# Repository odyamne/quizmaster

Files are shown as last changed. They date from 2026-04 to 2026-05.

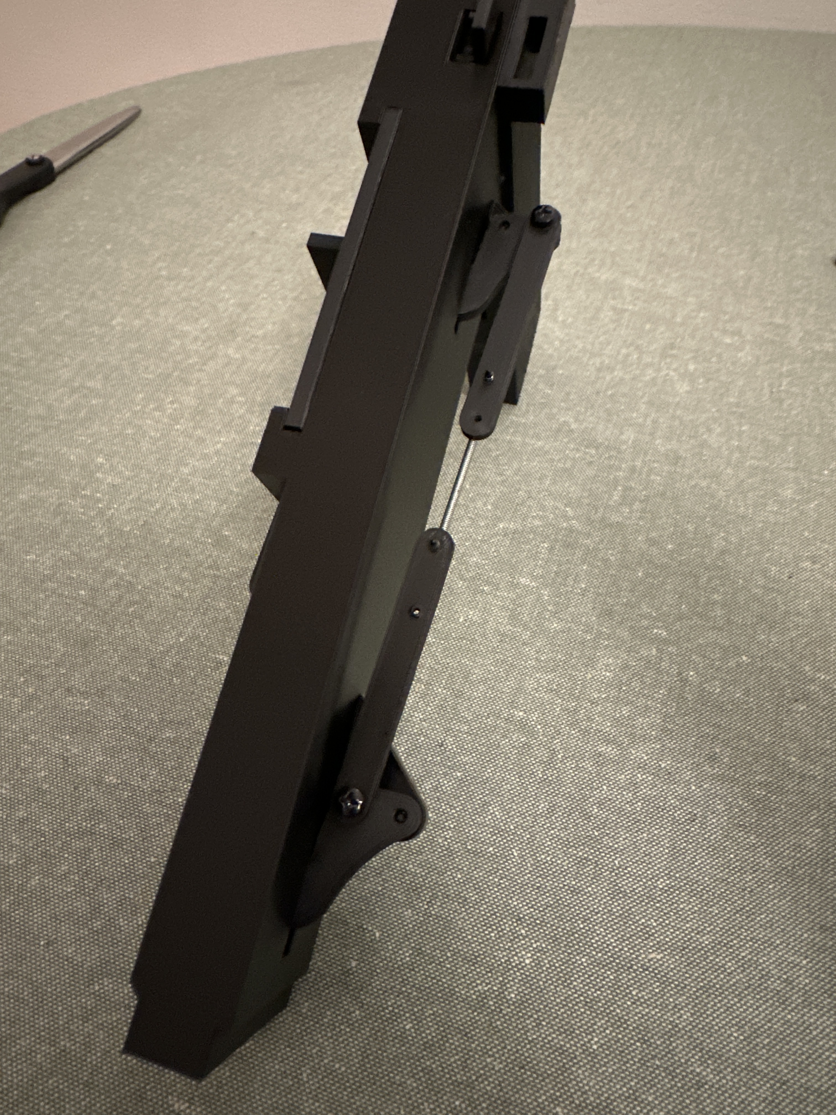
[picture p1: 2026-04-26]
Fotod/printimine/IMG_5341.JPG

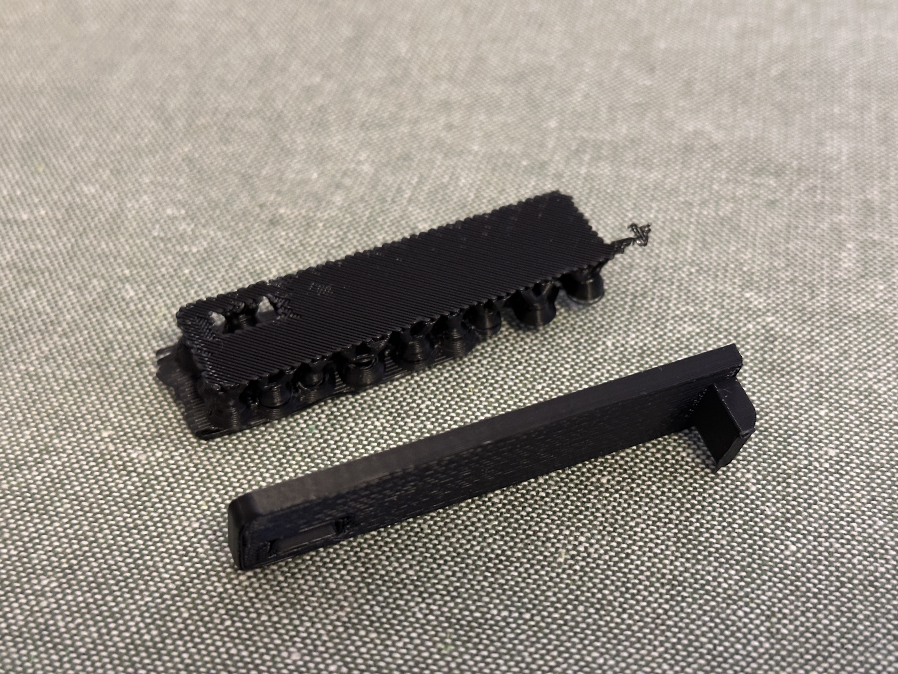
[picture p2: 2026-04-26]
Fotod/printimine/IMG_5337.JPG

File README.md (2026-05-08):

# DTI Interaktiivne Robot: Prototüüp "Quizmaster"

Käesolev repositoorium sisaldab Tallinna Ülikooli Digitehnoloogiate Instituudi (DTI) bakalaureusetöö raames arendatud sotsiaalse roboti prototüübi tehnilist dokumentatsiooni, tarkvara ja disainifaile. Projekti eesmärk on luua interaktiivne vahend, mis tutvustab IKT-valdkonda läbi mängustatud viktoriini ja füüsilise preemiamehhanismi.

## Repositooriumi struktuur

Süsteem on jaotatud neljaks põhivaldkonnaks, mis vastavad repositooriumi juurkataloogidele:

- **[/CAD](./CAD)** – Roboti korpuse ja mehaaniliste detailide mudelid (Solid Edge 2024).
  - `assembly/` – Seadme koostefailid (.par).
  - `stl/` – 3D-printimiseks valmis detailid.
  - `pleksi_loige.dft` – Joonis pleksiklaasi CNC- või laserlõikuse jaoks.
- **[/Fritzing](./Fritzing)** – Elektroonika komponentide ühendusskeem.
- **[/Lähtekood](./Lähtekood)** – Süsteemi tarkvaraline arhitektuur.
  - `esp32/` – Alamkontrolleri tarkvara (C++) servomootorite ja LED-ide juhtimiseks.
  - `frontend/` – Veebipõhine kasutajaliides (HTML/JS/CSS).
  - `main.py` – Kesksüsteemi loogika (Python/FastAPI).
  - `questions.json` – Muudetav viktoriini küsimuste baas.
- **[/Fotod](./Fotod)** – Visuaalne dokumentatsioon arendusprotsessist ja riistvara komponentidest.

## Tehniline teostus

### Põhifunktsioonid

- **Autonoomne tuvastus:** mmWave radari abil tajub robot lähenevaid inimesi ja algatab interaktsiooni.
- **Mängustatud viktoriin:** Interaktsioon toimub 7" ekraani ja taktiilset tagasisidet pakkuvate arkaadnuppude abil.
- **Mehaaniline väljastus:** Servomootoritega juhitud kaheastmeline premeerimissüsteem maiustuste väljastamiseks.
- **Multimeedia:** Animeeritud silmad ja sünteesitud eestikeelne kõne (TTS).

### Riistvaraline arhitektuur

Süsteem kasutab hajutatud arvutusmudelit:

- **Keskarvuti:** Raspberry Pi 4B - tegeleb backendi, frontendi, multimeedia ja anduritega.
- **Alamkontroller:** NodeMCU ESP32 - juhib servomootoreid ja LED-ribasid.
- **Toide:** X728 UPS HAT - stabiilse voolu tagamiseks ja `power_monitor.py` energiatarbe halduseks.
- **Signaali terviklikkus:** Kasutatud on loogikanivoo muundurit ja LED-ribade andmeliinidel 330 Ω takisteid.

### Disain ja valmistamine

Kõik detailid on modelleeritud **Solid Edge 2024** tarkvaraga. Valmistamisel on kasutatud 3D-printimise tehnoloogiat PLA plast filamendiga ja pleksiklaasi CNC-lõikust.

## Kasutamine

1.  **Riistvara:** Pane süsteem kokku järgides [/Fritzing](./Fritzing) kataloogis olevat elektriskeemi.
2.  **Süsteemi seadistamine:**
    - Paigalda vajalikud Pythoni teegid: `pip install -r requirements.txt`.
    - Laadi `esp32/` kood ESP32 mikrokontrollerisse kasutades selleks Arduino IDE.
    - Ühenda X728 UPS HAT autoboot viikudele "jumper".
3.  **Käivitamine:** Käivita kesksüsteem käsuga `python main.py`. Pärast toite ühendamist ja nupu vajutust käivitub roboti autonoomne režiim ning ootab interaktsiooni.

## Litsents

- **Tarkvara** ([/Lähtekood](./Lähtekood)): [MIT litsents](https://opensource.org/licenses/MIT).
- **Disain ja skeemid** ([/CAD](./CAD), [/Fritzing](./Fritzing)): [Creative Commons Attribution 4.0 International (CC BY 4.0)](https://creativecommons.org/licenses/by/4.0/).

## Autorid

- **Ander Aava & Taavi Vendt**
- **Juhendajad:** Kalle Kivi ja Triinu Jesmin
- **Tehniline konsultant:** Tanel Toova

---

_Tallinna Ülikool, Digitehnoloogiate Instituut (2026)_

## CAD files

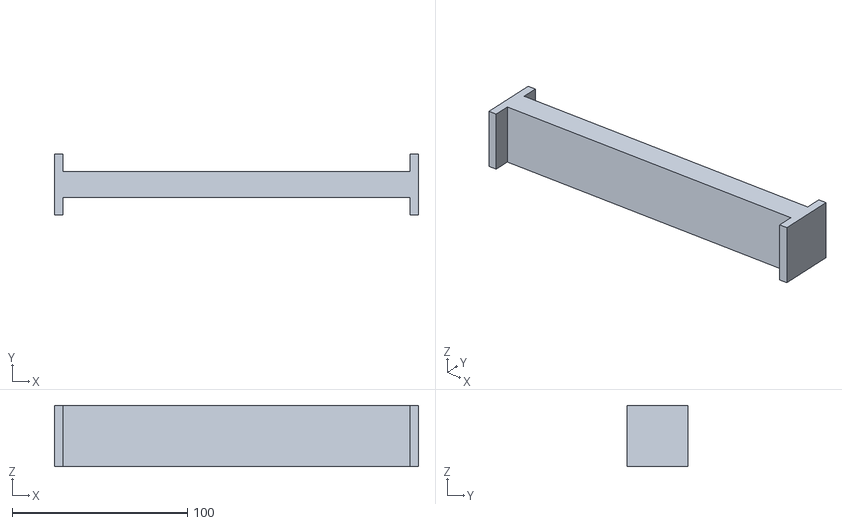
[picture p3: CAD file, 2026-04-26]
CAD/stl/salve_laadimis_abiline.stl
208.0 x 35.0 x 35.0

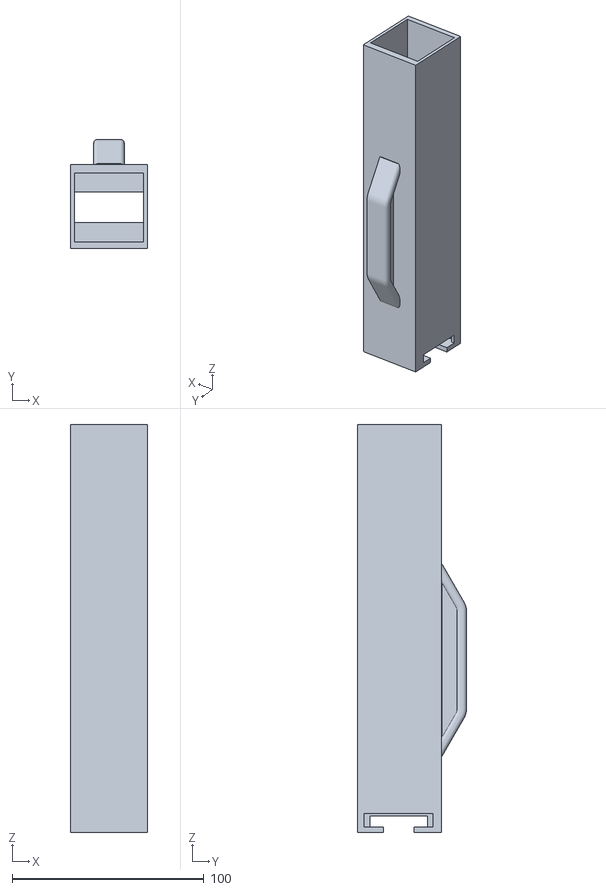
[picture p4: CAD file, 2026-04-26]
CAD/stl/teal/shoko_salv.stl
40.0 x 57.0 x 213.0

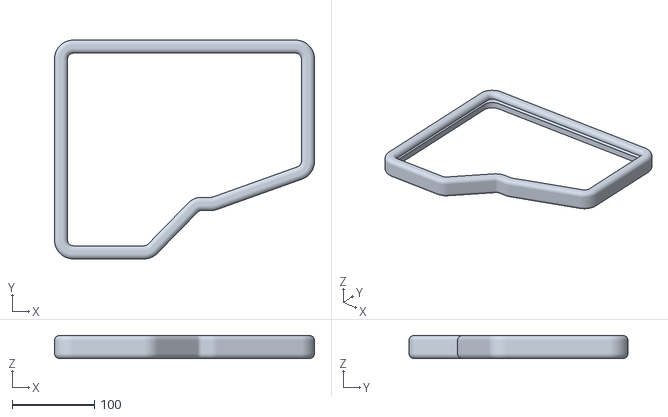
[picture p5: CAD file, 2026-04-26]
CAD/stl/transparent/led_trim.stl
316.0 x 266.0 x 28.0

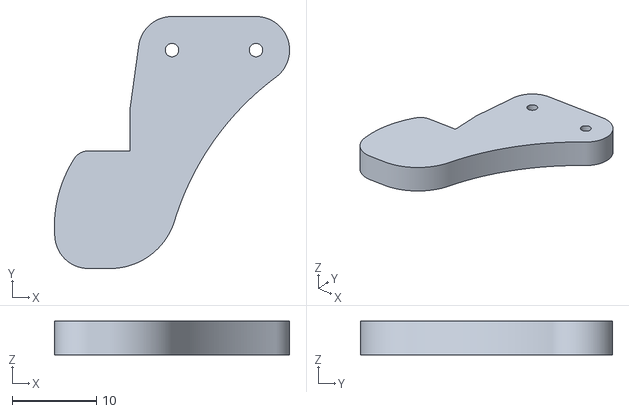
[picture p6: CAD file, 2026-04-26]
CAD/stl/white/shoko_pidur.stl
28.0 x 30.0 x 4.00

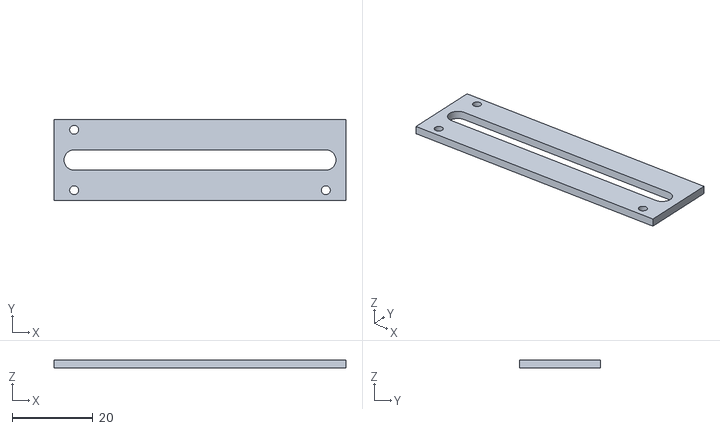
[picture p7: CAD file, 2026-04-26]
CAD/stl/teal/salve_lukusti_kate.stl
72.5 x 20.0 x 2.00

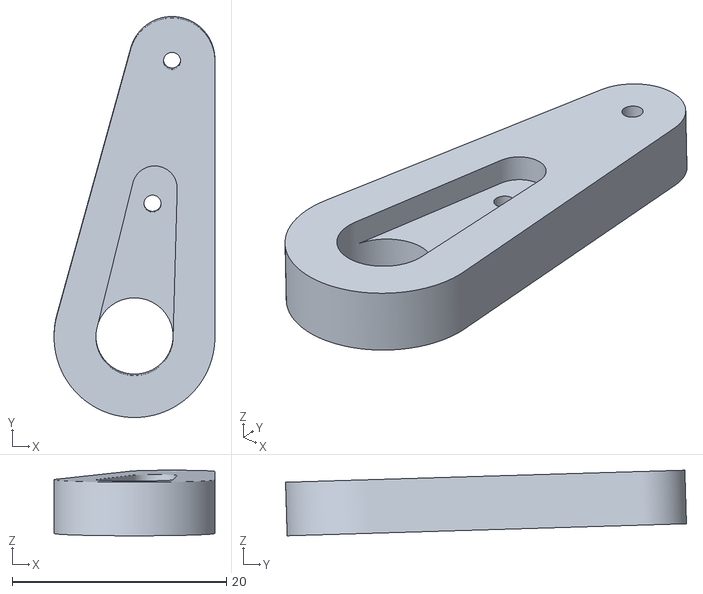
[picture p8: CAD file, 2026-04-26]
CAD/stl/white/crank_servole.stl
15.0 x 37.4 x 6.12

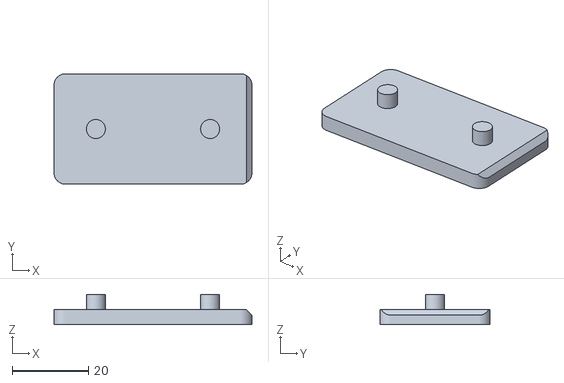
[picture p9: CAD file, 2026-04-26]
CAD/stl/teal/dispenser_laadija_kelk.stl
52.0 x 29.0 x 8.00

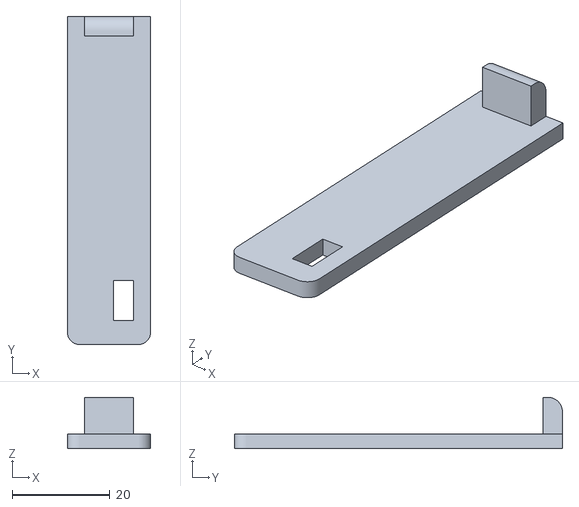
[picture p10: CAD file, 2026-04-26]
CAD/stl/white/dispenser_kelk_tommits.stl
17.0 x 67.0 x 10.5

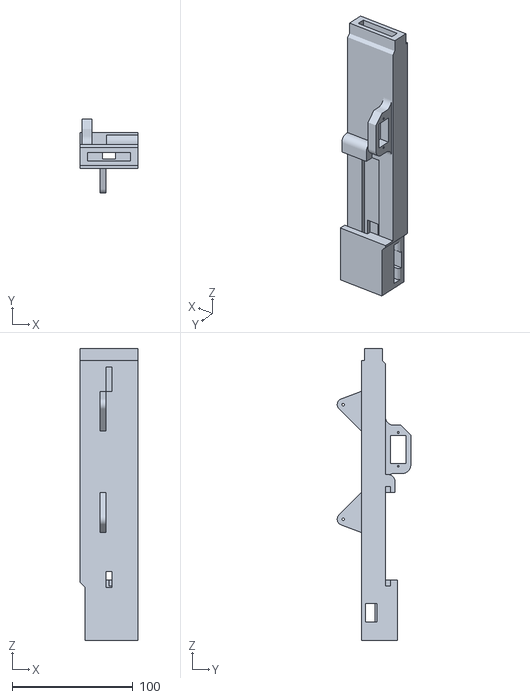
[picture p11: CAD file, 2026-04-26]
CAD/stl/teal/dispenser_kelk_raam.stl
48.0 x 61.0 x 242.0

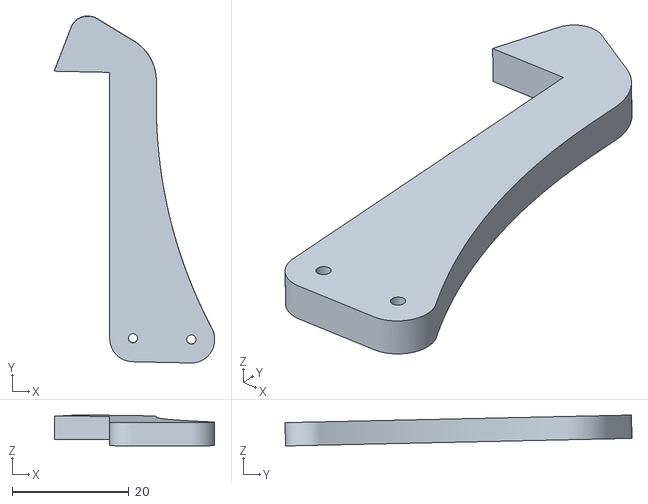
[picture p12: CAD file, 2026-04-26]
CAD/stl/white/uus_shoko_pidur.stl
27.5 x 59.5 x 5.30

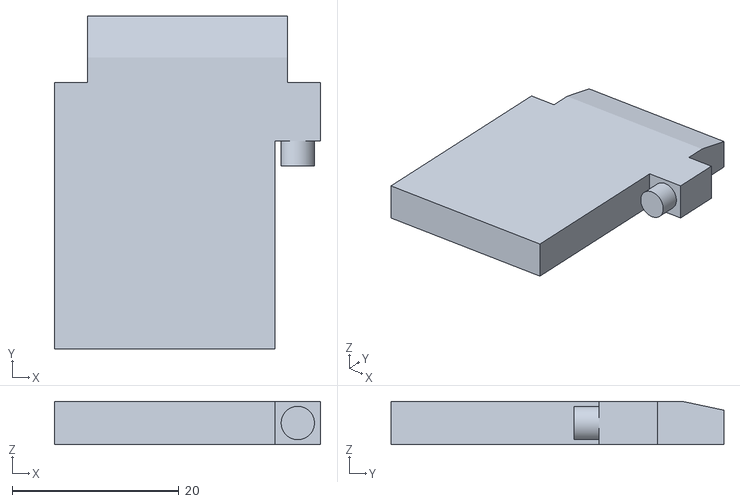
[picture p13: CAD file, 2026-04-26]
CAD/stl/teal/dispenser_kinnitus.stl
32.0 x 40.0 x 5.20

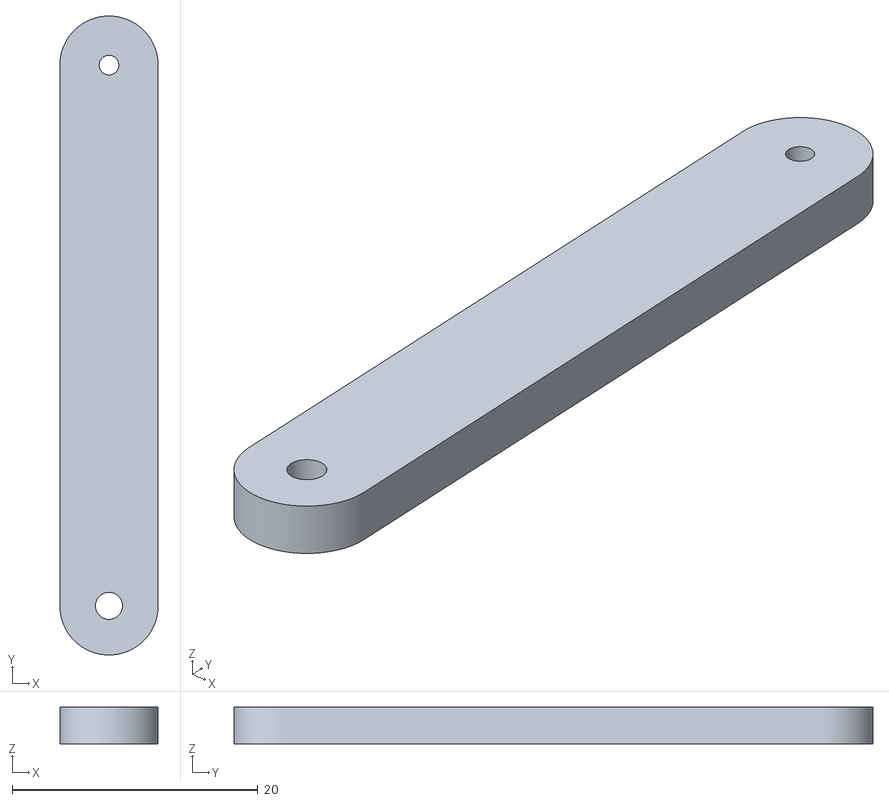
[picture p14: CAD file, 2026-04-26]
CAD/stl/white/piduri_link.stl
8.00 x 52.0 x 3.00

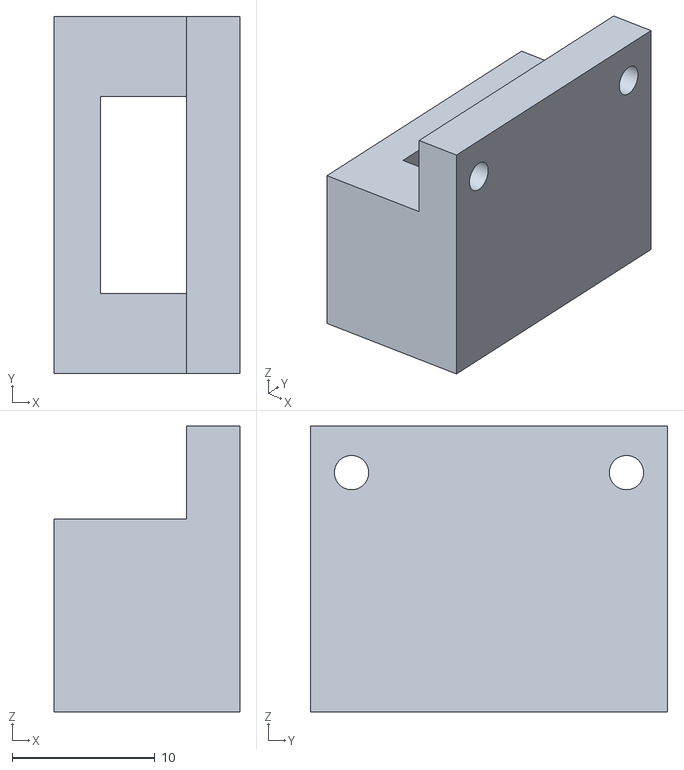
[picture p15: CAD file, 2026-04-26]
CAD/stl/teal/usb_a_pesa.stl
13.0 x 25.0 x 20.0

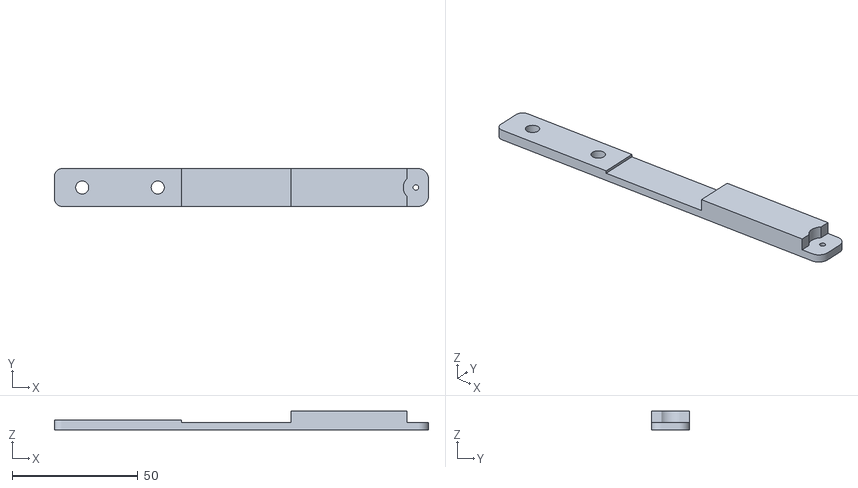
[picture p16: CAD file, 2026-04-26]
CAD/stl/white/dispenser_laadija_liugur.stl
148.5 x 15.0 x 7.50

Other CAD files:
CAD/stl/transparent/led_trim_mir.stl
CAD/stl/teal/salve_lukusti.stl
CAD/stl/white/salve_magnet_klots.stl
CAD/stl/teal/dispenser_crank_link.stl
CAD/stl/teal/PD_klamber.stl
CAD/stl/teal/crank_liiges.stl
CAD/stl/teal/ekraani_klamber.stl
CAD/stl/teal/servo_bottom_pesa_kaas.stl
CAD/stl/white/crank_kinnitus.stl
CAD/stl/white/dispenser_kelk_kate.stl
CAD/stl/white/dispenser_servo_crank.stl
CAD/stl/white/robot_kere_koost.stl

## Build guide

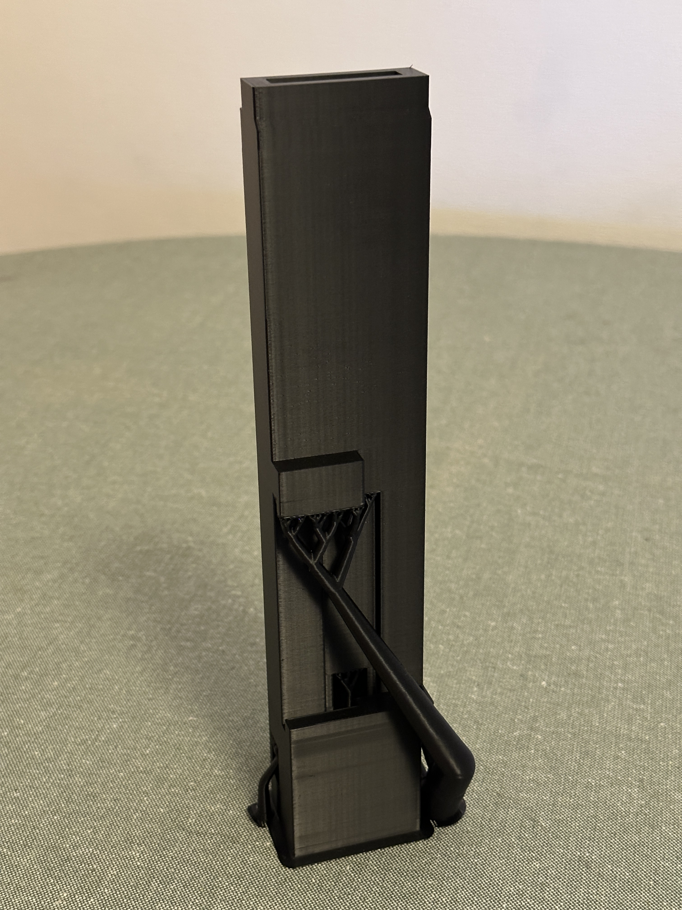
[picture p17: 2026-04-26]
Fotod/printimine/IMG_5334.JPG

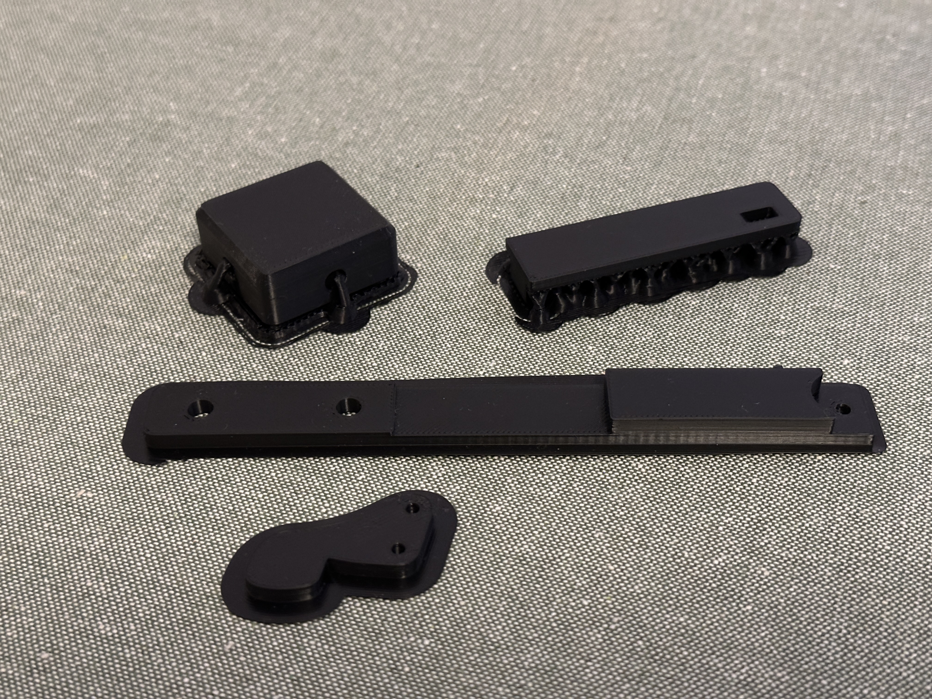
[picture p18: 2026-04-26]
Fotod/printimine/IMG_5335.JPG

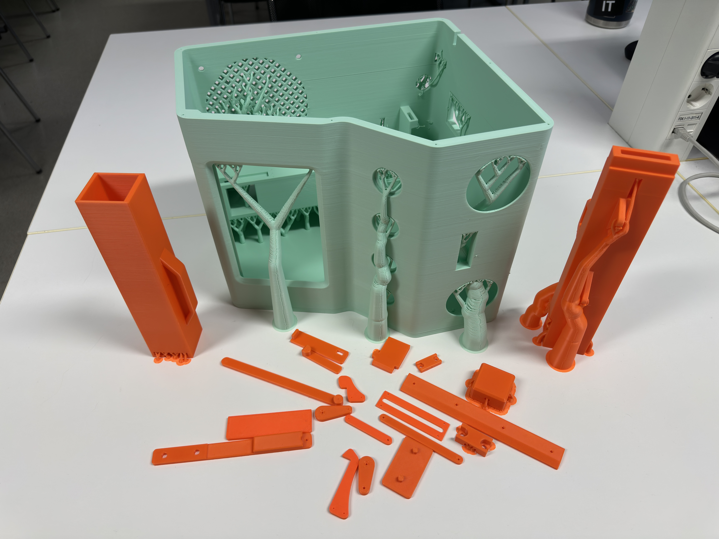
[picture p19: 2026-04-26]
Fotod/printimine/IMG_5527.JPG

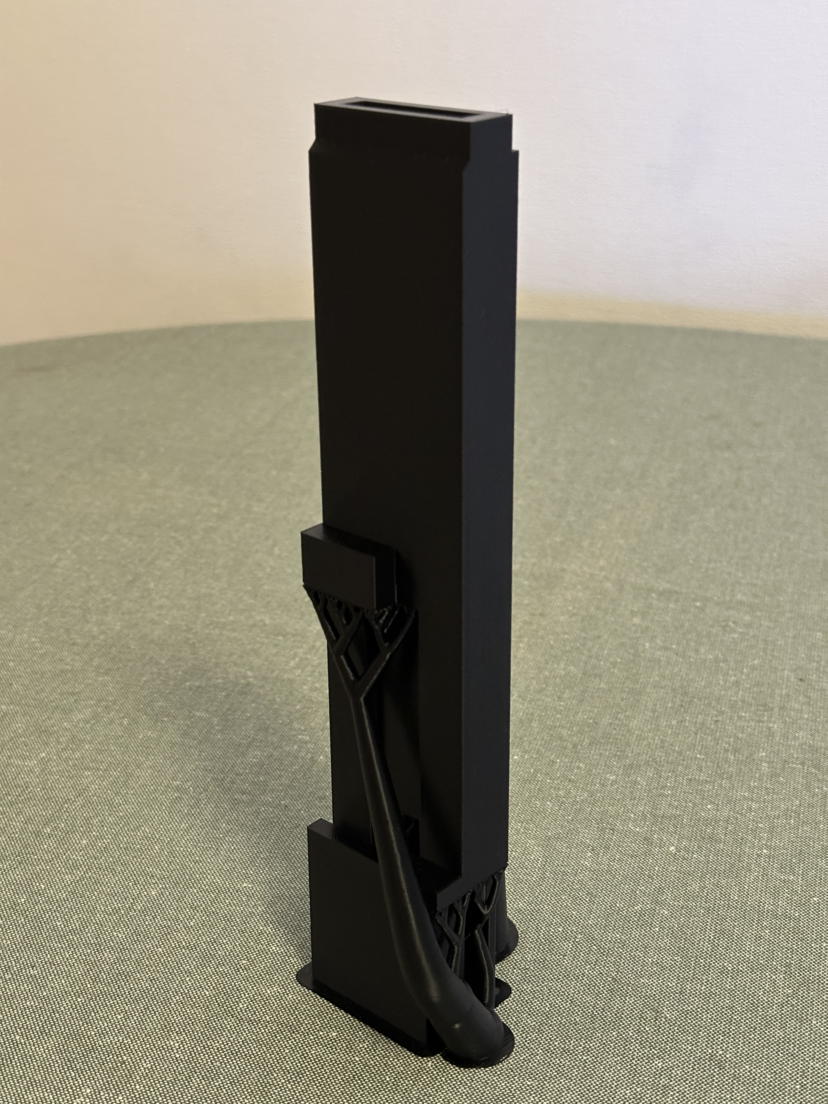
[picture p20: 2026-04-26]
Fotod/printimine/IMG_5333.JPG

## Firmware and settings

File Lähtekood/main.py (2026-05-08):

import asyncio
import json
import random
import serial
import time
from contextlib import asynccontextmanager
from fastapi import FastAPI, WebSocket, WebSocketDisconnect
from fastapi.staticfiles import StaticFiles
from gpiozero import Button, LED, DigitalInputDevice
import uvicorn

# ==========================================
# GLOBAALSED MUUTUJAD JA OLEKUD
# ==========================================
main_loop = None
STATE = "IDLE"  # Võimalikud: ERROR, IDLE, ACTIVE, QUIZ, REWARD

# Riistvara pordid
RADAR_PORT = '/dev/ttyAMA4'
ESP_PORT = '/dev/ttyUSB0'  # Või /dev/ttyACM0

# Quiz taimer
quiz_last_activity = 0
QUIZ_TIMEOUT = 30  # Sekundit, enne kui robot tüdineb

questions_db = []
current_question = None

# ==========================================
# ANDMEBAASI LAADIMINE
# ==========================================
def load_questions():
    try:
        with open("questions.json", "r", encoding="utf-8") as f:
            return json.load(f)
    except FileNotFoundError:
        print("VIGA: questions.json faili ei leitud!")
        return []

questions_db = load_questions()

def get_random_question():
    if not questions_db:
        return {"question": "VIGA: Andmebaas tühi!", "answers": {"A": "-", "B": "-", "C": "-", "D": "-"}, "correct_btn": "A"}
    return random.choice(questions_db)

# ==========================================
# ESP32 JA RADAR (JADAÜHENDUSED)
# ==========================================
esp_serial = None
radar_serial = None

try:
    esp_serial = serial.Serial(ESP_PORT, 115200, timeout=1)
    print("ESP32 ühendatud!")
except:
    print(f"VIGA: ESP32 ei leitud pordilt {ESP_PORT}")

try:
    radar_serial = serial.Serial(RADAR_PORT, 115200, timeout=1)
    print("Radar ühendatud!")
except:
    print(f"VIGA: Radariti ei leitud pordilt {RADAR_PORT}")

def send_esp_command(cmd: str):
    """Saadab käsu üle USB ESP32-le"""
    if esp_serial:
        try:
            esp_serial.write((cmd + '\n').encode('utf-8'))
        except Exception as e:
            print(f"ESP saatmise viga: {e}")

# ==========================================
# NUPUD JA HALL SENSOR
# ==========================================
hardware_events = asyncio.Queue()

try:
    btn_A = Button(17, pull_up=True, bounce_time=0.1) # Punane
    led_A = LED(27)
    btn_B = Button(23, pull_up=True, bounce_time=0.1) # Roheline
    led_B = LED(22)
    btn_C = Button(24, pull_up=True, bounce_time=0.1) # Sinine
    led_C = LED(25)
    btn_D = Button(16, pull_up=True, bounce_time=0.1)  # Kollane
    led_D = LED(13)
    
    # Hall sensor šokolaadi jaoks
    hall_sensor = DigitalInputDevice(18, pull_up=True)
    hardware_available = True
except Exception as e:
    print(f"GPIO viga: {e}")
    hardware_available = False

def turn_all_leds(state: bool):
    if not hardware_available: return
    if state:
        led_A.on(); led_B.on(); led_C.on(); led_D.on()
    else:
        led_A.off(); led_B.off(); led_C.off(); led_D.off()

# ==========================================
# OLEKUMASINA/FSM LOOGIKAL ALGORITM
# ==========================================
def change_state(new_state):
    global STATE, current_question, quiz_last_activity
    if STATE == new_state: return
    STATE = new_state
    print(f"--- UUS OLEK: {STATE} ---")

    # Teavita brauserit oleku muutusest
    if main_loop:
        main_loop.call_soon_threadsafe(hardware_events.put_nowait, {"event": "STATE_CHANGE", "state": STATE})

    if STATE == "IDLE":
        # turn_all_leds(False)
        send_esp_command("LED_IDLE")
        
    elif STATE == "ACTIVE":
        # Heli: "Hei! Astu ligi!"
        # Siin saad hiljem kutsuda nt: play_audio("tervitus.wav")
        # turn_all_leds(True)
        send_esp_command("LED_IDLE")

    elif STATE == "QUIZ":
        quiz_last_activity = time.time()
        turn_all_leds(True)
        current_question = get_random_question()
        if main_loop:
            main_loop.call_soon_threadsafe(hardware_events.put_nowait, {
                "event": "START_QUIZ",
                "question": current_question["question"],
                "answers": current_question["answers"],
                "correct_btn": current_question["correct_btn"]
            })
            
    elif STATE == "REWARD":
        turn_all_leds(False)
        # Heli: "Suurepärane! Siin on sulle auhind!"
        send_esp_command("LED_WIN")
        send_esp_command("DISPENSE")
        # Premeerimise lõpetab eraldi taustaprotsess (vaata allpool)

    elif STATE == "ERROR":
        turn_all_leds(False)
        send_esp_command("LED_OFF")

# ==========================================
# SÜNDMUSTE KÄSITLEJAD (Nupud & Sensor)
# ==========================================
def on_button_pressed(btn_name):
    global quiz_last_activity
    
    if STATE == "ERROR":
        # Kui oleme hoolduses, ainult ROHELINE nupp teeb midagi (kinnitab täitmise)
        if btn_name == "B" and not hall_sensor.is_active:
            print("Hooldus kinnitatud. Masin korras!")
            change_state("IDLE")
        return

    if STATE == "ACTIVE":
        # Inimene vajutas nuppu, lähme viktoriini!
        change_state("QUIZ")
        return

    if STATE == "QUIZ":
        quiz_last_activity = time.time() # Nullime taimeri
        
        # Saada vajutus UI-le visuaaliks
        if main_loop:
            main_loop.call_soon_threadsafe(hardware_events.put_nowait, {"event": "BUTTON_PRESS", "button": btn_name})
        
        # Kontrollime vastust
        if btn_name == current_question["correct_btn"]:
            change_state("REWARD")
            # Käivitame asünkroonse ootaja, mis viib tagasi IDLE olekusse pärast servo tsüklit
            if main_loop:
                main_loop.create_task(reward_sequence())
        else:
            # Heli: "Vale vastus, proovi uuesti!"
            pass 

def on_hall_sensor_changed():
    """Kutsutakse välja, kui magnet fikseerib salve tühjenemise"""
    if hall_sensor.is_active:
        print("HÄIRE: Šokolaad on otsas!")
        change_state("ERROR")
    else:
        # Magnet võeti ära, järelikult hooldaja võttis salve välja
        if STATE == "ERROR":
            print("Hooldus: Salv eemaldatud. Ootan rohelist nuppu...")
            if main_loop:
                main_loop.call_soon_threadsafe(hardware_events.put_nowait, {"event": "MAINTENANCE_MODE"})

if hardware_available:
    btn_A.when_pressed = lambda: on_button_pressed("A")
    btn_B.when_pressed = lambda: on_button_pressed("B")
    btn_C.when_pressed = lambda: on_button_pressed("C")
    btn_D.when_pressed = lambda: on_button_pressed("D")
    
    # Magnetanduri sündmused
    hall_sensor.when_activated = on_hall_sensor_changed
    hall_sensor.when_deactivated = on_hall_sensor_changed

# ==========================================
# TAUSTAPROTSESSID (Radar & Taimerid)
# ==========================================
async def reward_sequence():
    """Ootab servo väljastustsükli lõppu ja taastab ooterežiimi"""
    await asyncio.sleep(8) # ESP tsükkel võtab ca 8 sek
    if STATE == "REWARD": # Veendume, et vahepeal pole magnet salv tühjenenud
        change_state("IDLE")

async def led_blinker_task():
    """Haldab nuppude LED-ide animatsioone"""
    if not hardware_available:
        return
        
    # Nuppude LED-ide haldus
    leds = [led_A, led_B, led_C, led_D]
    wave_index = 0
    wave_direction = 1
    blink_state = False

    while True:
        if STATE == "IDLE":
            # Lainetuse (wave) rütm edasi-tagasi
            for i, led in enumerate(leds):
                if i == wave_index:
                    led.on()
                else:
                    led.off()
            
            # Arvutame järgmise tule indeksi
            wave_index += wave_direction
            if wave_index >= len(leds) - 1:
                wave_direction = -1  # Pöörab suuna tagasi
            elif wave_index <= 0:
                wave_direction = 1   # Pöörab suuna edasi
                
            await asyncio.sleep(0.3) # Laine liikumise kiirus (väiksem = kiirem)

        elif STATE == "ACTIVE":
            # Kõik nupud vilguvad sünkroonis
            blink_state = not blink_state
            turn_all_leds(blink_state)
            await asyncio.sleep(0.5) # Vilkumise kiirus (0.5s sees, 0.5s väljas)
            
        else:
            # Muudes olekutes (QUIZ, REWARD, ERROR) me animatsiooni ei tee
            # Tulede staatilise oleku määrab `change_state()` funktsioon
            await asyncio.sleep(0.5)

async def radar_listener():
    last_seen_time = 0
    presence_start_time = None  # Stopperi algusaeg
    REQUIRED_PRESENCE = 5.0     # Mitu sekundit peab inimene paigal seisma
    
    while True:
        if radar_serial and radar_serial.in_waiting > 0:
            try:
                line = radar_serial.readline().decode('utf-8').strip()
                # Puhastame sisendi ja teisendame numbriks
                distance = int(''.join(filter(str.isdigit, line))) 
                
                # Silumiseks saadame endiselt andmed HUDi (lõpus eemaldame)
                if main_loop:
                    main_loop.call_soon_threadsafe(hardware_events.put_nowait, {
                        "event": "RADAR_DEBUG", 
                        "distance": distance
                    })

                if distance < 100: 
                    last_seen_time = time.time() # Viimati nähtud üldse
                    
                    # Kui keegi just sisenes, paneme stopperi käima
                    if presence_start_time is None:
                        presence_start_time = time.time()
                        print("Radar: Keegi sisenes tsooni, alustan ootamist...")

                    # Kontrollime, kas 5 sekundit on täis
                    elapsed = time.time() - presence_start_time
                    if STATE == "IDLE" and elapsed >= REQUIRED_PRESENCE:
                        print(f"Radar: Inimene on viibinud tsooni {REQUIRED_PRESENCE}s. Aktiveerin!")
                        change_state("ACTIVE")
                else:
                    # Kui vaateväli on tühi, nullime stopperi koheselt
                    if presence_start_time is not None:
                        print("Radar: Tsoon tühjenes, nullin stopperi.")
                    presence_start_time = None
                    
            except Exception as e:
                # ignoreeri lugemisvigu
                pass
                
        # Kui oleme ACTIVE olekus ja kedagi pole näha olnud 3 sekundit, läheb IDLE-sse
        if STATE == "ACTIVE" and (time.time() - last_seen_time > 3.0):
            change_state("IDLE")
            presence_start_time = None # Igaks juhuks nullime ka siin
            
        await asyncio.sleep(0.05)

async def quiz_timeout_watcher():
    """Põgenemise stsenaarium: Viskab mängust välja, kui nuppu ei vajutata"""
    while True:
        if STATE == "QUIZ" and (time.time() - quiz_last_activity > QUIZ_TIMEOUT):
            print("TIMEOUT: Inimene lahkus mängu ajal.")
            change_state("IDLE")
        await asyncio.sleep(1)

# ==========================================
# FASTAPI JA SÜSTEEMI KÄIVITUMINE
# ==========================================
@asynccontextmanager
async def lifespan(app: FastAPI):
    global main_loop
    main_loop = asyncio.get_running_loop()
    
    # Käivitame taustaprotsessid
    asyncio.create_task(broadcast_hardware_events())
    asyncio.create_task(radar_listener())
    asyncio.create_task(quiz_timeout_watcher())
    asyncio.create_task(led_blinker_task())
    
    # Kontrollime kohe alguses, kas šokolaadi on
    if hardware_available and hall_sensor.is_active:
        change_state("ERROR")
    else:
        change_state("IDLE")
        
    yield

app = FastAPI(lifespan=lifespan)
app.mount("/gui", StaticFiles(directory="frontend", html=True), name="gui")
active_websockets = []

async def broadcast_hardware_events():
    global current_question # Vajalik, et teaksime, mis on õige vastus
    
    while True:
        event = await hardware_events.get()
        
        # 1. SAADAME SÜNDMUSE BRAUSERISSE (nagu varem)
        # See paneb nupu ekraanil helendama
        for ws in active_websockets:
            try:
                await ws.send_json(event)
            except:
                pass

        # 2. LOGIKA KONTROLL: Kui on käimas QUIZ ja vajutati nuppu
        if STATE == "QUIZ" and event.get("event") == "BUTTON_PRESS":
            user_choice = event.get("button") # Nt "A"
            
            # Kontrollime, kas current_question on olemas ja sisaldab õiget vastust
            if current_question and "correct_btn" in current_question:
                correct_choice = current_question["correct_btn"]

                if user_choice == correct_choice:
                    print(f"RAAL-AJU: Õige vastus! ({user_choice})")
                    change_state("REWARD")
                else:
                    print(f"RAAL-AJU: Vale vastus! Valiti {user_choice}, aga õige oli {correct_choice}")
                    
                    # Teavitame brauserit, et vastus oli vale
                    for ws in active_websockets:
                        try:
                            await ws.send_json({
                                "event": "QUIZ_RESULT",
                                "result": "WRONG",
                                "button": user_choice
                            })
                        except:
                            pass
                    
                    # Jätame veateate 3-ks sekundiks ekraanile ja siis läheme ootele
                    await asyncio.sleep(3)
                    
                    if STATE == "QUIZ":
                        # Taastame ekraani, saates SAMA küsimuse uuesti.
                        # Kuna app.js juba teab, et START_QUIZ puhastab vanad stiilid ära,
                        # siis ekraan läheb ilusti tagasi algsesse "ootan vastust" seisu.
                        for ws in active_websockets:
                            try:
                                await ws.send_json({
                                    "event": "START_QUIZ",
                                    "question": current_question["question"],
                                    "answers": current_question["answers"],
                                    "correct_btn": current_question["correct_btn"]
                                })
                            except:
                                pass
        
        # Märgime järjekorra elemendi töödelduks
        hardware_events.task_done()
        
@app.websocket("/ws")
async def websocket_endpoint(websocket: WebSocket):
    await websocket.accept()
    active_websockets.append(websocket)
    # Saadame kohe algse oleku uuele brauserile
    await websocket.send_json({"event": "STATE_CHANGE", "state": STATE})
    try:
        while True:
            await websocket.receive_text() # Hoiame ühendust elus
    except WebSocketDisconnect:
        active_websockets.remove(websocket)

if __name__ == "__main__":
    uvicorn.run(app, host="0.0.0.0", port=8000)

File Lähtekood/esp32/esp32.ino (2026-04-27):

#include <Arduino.h>
#include <ESP32Servo.h>
#include <Adafruit_NeoPixel.h>

// --- NeoPixel Configuration ---
#define PIN_1 4
#define PIN_2 5
#define N_LEDS 60
#define BRIGHTNESS 200 // 40% brightness

// --- Servo Configuration ---
const int servoPin1 = 19;
const int servoPin2 = 18;

// Instantiate Objects
Adafruit_NeoPixel strip1 = Adafruit_NeoPixel(N_LEDS, PIN_1, NEO_GRB + NEO_KHZ800);
Adafruit_NeoPixel strip2 = Adafruit_NeoPixel(N_LEDS, PIN_2, NEO_GRB + NEO_KHZ800);
Servo servo1;
Servo servo2;

void setup() {
  Serial.begin(115200);
  
  // NeoPixels algseadistus
  strip1.begin();
  strip2.begin();
  strip1.setBrightness(BRIGHTNESS);
  strip2.setBrightness(BRIGHTNESS);
  
  // Lülitame alguses ootevärvi peale (sinakas-roheline)
  setLEDs(107, 202, 186);

  // Servode algseadistus
  ESP32PWM::allocateTimer(0);
  ESP32PWM::allocateTimer(1);
  servo1.setPeriodHertz(50);
  servo2.setPeriodHertz(50);
  
  // Hoiame servod alguses lahti ühendatuna, et vältida surisemist
  // Kinnitame nad alles siis, kui liikumine reaalselt algab.
  Serial.println("ESP32 VALMIS. Ootan käsklusi...");
}

void loop() {
  // Kuulame, kas Raspberry Pi saatis meile USB kaudu sõnumi
  if (Serial.available() > 0) {
    String cmd = Serial.readStringUntil('\n');
    cmd.trim(); // Eemaldame tühikud ja reavahetused

    if (cmd == "DISPENSE") {
      runDispenseCycle();
    } 
    else if (cmd == "LED_WIN") {
      setLEDs(0, 255, 0); // Roheline võiduvärv
    }
    else if (cmd == "LED_IDLE") {
      setLEDs(107, 202, 186); // Algne ootevärv
    }
    else if (cmd == "LED_OFF") {
      setLEDs(0, 0, 0); // Tuled kustu
    }
  }
}

// --- ABIFUNKTSIOONID ---

void setLEDs(int r, int g, int b) {
  strip1.fill(strip1.Color(r, g, b));
  strip2.fill(strip2.Color(r, g, b));
  strip1.show();
  strip2.show();
}

void runDispenseCycle() {
  Serial.println("Alustan väljastustsüklit!");
  
  // Ühendame servod uuesti külge
  servo1.attach(servoPin1, 570, 2465);
  servo2.attach(servoPin2, 570, 2465);
  
  // Turvaline algasend
  servo1.write(0);
  servo2.write(0);
  delay(1000);

  // Tsükkel
  servo1.write(180);
  delay(2000);

  servo2.write(180);
  delay(2000);

  servo2.write(0);
  delay(2000);

  servo1.write(0);
  delay(2000); // Ootab füüsilise liikumise lõppu

  // Vabastame servod (Jitteri tapja)
  servo1.detach();
  servo2.detach();
  
  Serial.println("Väljastustsükkel lõpetatud!"); // Pi ootab seda vastust!
}

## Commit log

2026-04-25 added Fritzing schematic
    [elektriskeem.fzz]
2026-04-26 upload CAD + Fotod
    [Asm2.cfg, PD_klamber.stl, crank_kinnitus.stl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]
